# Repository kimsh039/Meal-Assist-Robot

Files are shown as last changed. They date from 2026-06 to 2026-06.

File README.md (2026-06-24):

# 🦾 LUMEN: 3D프린팅 기술을 활용한 인체공학적 다관절 식사 보조 로봇팔
> **"누구나, 언제, 어디서나 스스로 식사할 수 있는 세상"**

인하대학교 **LUMEN(사람의 삶을 밝히는 기술)** 팀이 개발한 **3D프린팅 기반의 인체공학적 다관절 식사 보조 로봇팔** 프로젝트입니다. 상지 장애인, 노약자, 근골격계 환자 등 식사 자립이 어려운 분들의 독립적인 일상을 지원하며, AI 비전 인식 및 음성 제어 기술을 결합하여 저비용·경량·고정밀·안전성을 모두 만족하는 인간 중심 지능형 보조 로봇 시스템을 구현했습니다.

본 프로젝트는 **2025 창의적 종합설계 경진대회**에서 **장관상(2등)**을 수상하였습니다.

---
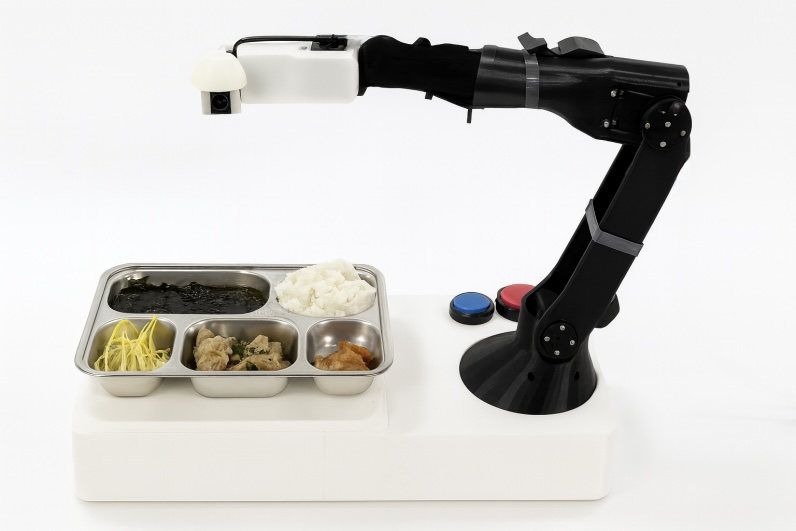
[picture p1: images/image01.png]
product


## 🏆 수상 실적
- **대회명**: 2025 캡스톤 디자인 및 창의아이디어 경진대회
- **상격**: **대상**
- **대회명**: 2025 인하 종합설계 경진대회 (인하공학교육혁신센터 주최/주관)
- **상격**: **인하대학교 총장상** 
- **대회명**: 2025 창의적 종합설계 경진대회 본선
- **상격**: **장관상(2등)**

---

## ✨ 핵심 특장점
- **정확성 (AI Vision)**: AI 카메라가 음식 종류와 입 위치를 실시간으로 인식하여 사용자 맞춤 최적 궤적을 생성합니다.
- **안전성 (Safety First)**: ISO 13850 국제표준 기반 비상정지 시스템과 전류센서 감지를 통해 이상 발생 시 0.1초 내로 전원을 긴급 차단합니다.
- **경량성 (Lightweight)**: 3D프린팅(PLA) 부품 설계로 전체 무게를 약 **1.5 kg** 이하로 구현하여 기존 금속 프레임 대비 약 60% 경량화 및 높은 휴대성을 확보했습니다.
- **경제성 (Cost-Effective)**: 제작 단가를 약 60~70% 절감하여 기존 고가의 해외 제품(1,000만 원 이상) 대비 압도적인 가격 경쟁력(400만 원 이하 공급 가능)을 가집니다.
- **확장성 (Smart Healthcare)**: 보호자용 앱을 통해 실시간 식사 영상을 모니터링하고 영양 및 식습관 데이터를 관리할 수 있습니다.

---

## ⚙️ 시스템 아키텍처 및 주요 기술

### 1. 하드웨어 & 인체공학 설계
- **다관절 구조 (6 DOF)**: 인체 팔의 움직임을 모사하여 숟가락의 궤적이 접시에서 입까지 자연스럽게 연결되도록 설계 (Inventor 및 NX 활용).
- **하이브리드 제어 인터페이스**: 사용자의 신체 조건에 맞춰 선택할 수 있는 3종 조작 방식(풋스위치, 손스위치, 마이크) 제공.
- **지속성**: 2주 이상 사용 가능한 고효율 배터리 탑재.

### 2. AI 비전 및 소프트웨어 시스템
- **음식 객체 인식**: `YOLOv8` 모델을 적용하여 식사 종류(국밥, 반찬, 죽 등)를 탐지하고 포크/스푼 모션을 자동 전환.
- **입 위치 추적 (Mouth Tracking)**: 실시간으로 사용자의 얼굴 및 입 좌표를 추적하여 정밀한 음식 전달 궤적 자동 계산.
- **음성 명령 인터페이스**: LLM 기반 음성명령 제어를 통해 손을 쓰지 않고도 원활한 식사 동작 수행 가능.

### 3. 제어 알고리즘
- **역기구학 (Inverse Kinematics)**: 다자유도 좌표 계산 및 회전각 제어 알고리즘 구현.
- **부드러운 궤적 생성**: Quadratic Programming 알고리즘을 활용하여 모터의 가속도를 최소화하고 흔들림 없는 안정적인 식사 동작 구현.
- **고정밀 제어**: FOC(Field-Oriented Control) 기반 모터 제어로 관절별 제어 정확도 `±0.5°` 이내 유지.

---

## 🛠️ 기술 스택 (Tech Stack)
- **Hardware**: Arduino, Raspberry Pi, Jetson Orin Nano, FOC Motor, Custom 3D Printed Parts (PLA)
- **Software & Control**: Python, C++, ROS (Robot Operating System)
- **AI & Vision**: YOLOv8, OpenCV, MediaPipe (Mouth Tracking), LLM (Voice Control)
- **3D Modeling**: Autodesk Inventor, Siemens NX

---

## 👥 팀원 및 역할 분담 (LUMEN)

| 성명 | 역할 | 담당 업무 |
| :--- | :--- | :--- |
| **조예은** | **PM** | 프로젝트 PM, 전체 일정 관리 및 기획 통합 |
| **전병철** | **하드웨어 제작** | 다관절 로봇팔 메커니즘 설계 및 하드웨어 통합 |
| **박원빈** | **제어 제작** | 임베디드 시스템 구축, 역기구학 및 모터 제어 알고리즘 구현 |
| **이상현** | **인공지능 제작** | YOLOv8 기반 음식 인식 및 입 위치 추적(Mouth Tracking) 모델 개발 |
| **김소희** | **제어 시스템 제작** | 전기회로 설계, 센서 연동 및 인터페이스 제어 보조 |
| **강수영** | **하드웨어 설계/제작** | Inventor/NX 활용 3D 모델링 및 3D 프린팅 부품 가공 |

---

## 📈 시장성 및 기대효과
- **B2B & B2C 시장 진출**: 요양병원, 재활시설 등 의료기관 납품(B2B)과 가정용 보조기기 판매(B2C) 구조 구축.
- **AI 헬스케어 연계**: 축적된 사용자의 식습관 및 영양 데이터를 활용하여 장기적인 맞춤형 디지털 헬스케어 서비스로 확장 가능.
- **사회적 가치**: 돌봄 인력 부족 문제 해결 및 사회적 약자의 자립적 환경 조성으로 인간 존엄성 회복 기여.

---

## 📚 참고문헌
1. 보건복지부(2024), "보건복지통계연보".
2. Ho-Chull Lee, Yong-Kwan Ji, & Jahng-Hyon Park(2019), "Geometric Analysis of Inverse Kinematics and Control for 7-DOF Robot Arm", 대한기계학회.
3. Minchang Sung & Youngjin Choi(2020), "Smooth Trajectory Generation Method Using Quadratic Programming", 한국로봇학회.

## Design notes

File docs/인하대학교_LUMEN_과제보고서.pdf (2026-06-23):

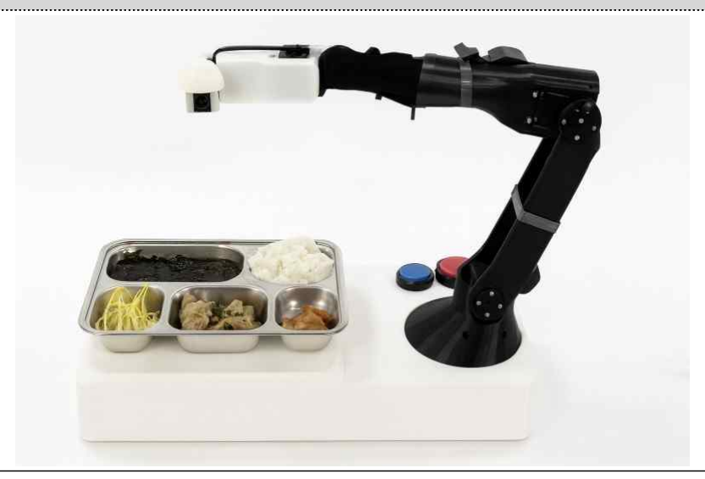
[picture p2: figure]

- 1 -

# 「2025 창의적 종합설계 경진대회」과제보고서

대 학 명 | 인하대학교 | 팀 명 | 국문 루멘 영문 LUMEN(사람의 삶을 밝히는 기술)
작 품 명 | 국문 3D프린팅 기술을 활용한 인체공학적 다관절 식사 보조 로봇팔 영문 A 3D-Printed Ergonomic Multi-Joint Assistive Robotic Arm for eating
제작기간 | 2025년 4월 28일 ~ 2025년 10월 28일
참가분야 | ■ 일 반 □ 다학제융합형 ■ 산학협력형* (산업체인사멘토링) ■ 사회기여형* (사회적약자 기여형)
지식재산권 | □ 해당 ■ 해당없음
포상실적 | 대회명 | 주최/주관 | 상격 | 수상일시 | 부상내역
2025 인하 종합설계 경진대회 | 인하공학교육혁신센터 | 인하대학교 총장상 | 2025.09.11 | 상금 80만원

작품
내용요약

식사 보조가 필요한 인구가 지속적으로 증가하는 가운데, 상지 장애나 근골격계 질환, 노화 등으로 인해 스스로 식사하기 어려운 사람들은 일상 속 자존감 상실과 돌봄 부담의 문제를 겪고 있다. 이러한 사회적 요구에 대응하기 위해 개발된 인체공학적 다관절 식사 보조 로봇 팔은 3D프린팅 기술을 활용해 경량화와 맞춤 설계를 구현하고, AI 기반 시각 인식 및 음성 제어 시스템을 결합하여 누구나 손쉽게 사용할 수 있는 식사 보조 솔루션을 제시한다. 로봇팔은 YOLOv8 기반 음식 객체 인식과 입 위치 추적 기술을 통해 사용자의 동작을 실시

간 분석하고, 음성 명령 또는 스위치 입력만으로 정확하고 부드러운 식사 동작을 수행한다. 또한 ISO 13850 국제표준에 따라 긴급정지 기능을 탑재하여 사용 중 사고를 방지하고, 1.5 kg

이하의 경량 구조와 2주 이상 사용 가능한 배터리를 적용해 휴대성과 안정성을 동시에 확보 하였다. 3D프린팅 부품 사용으로 제작 단가를 약 60% 절감했으며, 다양한 신체 조건에 맞춘 맞춤형 생산이 가능하다. 이러한 기술적 접근을 통해 사용자는 타인의 도움 없이 독립적인 식사를 경험할 수 있고, 보호자는 전용 애플리케이션을 통해 식사 영상을 실시간으로 확인하 며 영양 데이터를 관리할 수 있다. 복지 및 의료 산업 규모는 국내 약 3조 원, 해외 약 40조 원 이상으로 형성되어 있어 시장

성장 잠재력이 크다. 기존 제품 대비 낮은 가격과 높은 범용성을 기반으로 B2B(요양병원·재 활시설)와 B2C(가정용) 시장 진출이 가능하며, 장기적으로는 AI 헬스케어 서비스와 연계한 지 속 가능한 수익 창출 구조를 구축할 수 있다. 이 로봇팔은 단순한 보조기기를 넘어, 경제성 과 기술혁신, 인간 존엄의 회복을 동시에 실현하는 차세대 복지 로봇으로서의 의의를 지닌다. 작품사진

- 2 -

### 1. 과제의 목적, 개발동기 및 필요성

LUMEN이 수행한‘3D프린팅 기술을 활용한 인체공학적 다관절 식사 보조 로봇팔’은 상지 장애인, 노약자, 근골격계 환자 등 식사 자립이 어려운 사람들의 자립적 식사 활동을 지원하기 위해 고안되었

다. AI 기반의 인식 기술과 인체공학적 설계, 3D프린팅 제작 방식을 결합하여 저비용·경량·고정 밀·안전성을 모두 만족시키는 것이 핵심 목표이다. 현재 국내 약 91만 명이 식사 자립에 어려움을 겪고 있으며, 간병인 부족 및 고비용(월 400만 원 이상)의 돌봄 구조로 인해 사회적 부담이 심화되고 있다. 또한 기존 식사 보조 로봇은 대부분 고가(1,000만 원 이상)이거나 전용 식기만 사용 가능한 제 한된 구조를 갖고 있어 실제 보급이 어렵다. 이러한 문제 인식에서 출발한 LUMEN의 로봇팔은‘누구 나, 언제, 어디서나 스스로 식사할 수 있는 세상’을 구현하기 위해 개발되었다. 이 시스템은 YOLOv8 기반 음식 객체 인식, 입 위치 추적(Mouth Tracking), LLM 기반 음성명령 제

어 등을 결합해 사용자의 상황에 따라 정밀하게 동작하며, ISO 13850 국제표준 기반 긴급정지 기능, 2주 이상 사용 가능한 배터리, 경량 구조를 통해 안전성과 휴대성을 동시에 확보했다. 또한 3D프린팅 을 활용해 금속 구조물 대비 제작비를 대폭 절감하고, 사용자의 신체 조건에 맞춘 맞춤형 설계를 가 능하게 했다. 기존 식사 보조 로봇(예: 미국 OBI Eating Device, 스웨덴 Bestic, 특허 US 9066615B2 및 WO

2022055443A1 등)은 대체로 금속 기반 구조에 고가 부품을 사용하고, 전용 식기나 고정된 자세를 필 요로 하는 한계가 있었다. 이에 비해 LUMEN 로봇팔은 3D프린팅 경량화, 다관절 구조를 통한 자연스 러운 움직임, AI·음성인식 통합 인터페이스, 범용 식기 호환성, 낮은 제작비 등에서 확연한 차별성을 지닌다. 단순한 보조기기 개발을 넘어, 경제적 부담을 낮추고 인간의 존엄과 자립을 회복시키는 복지기술 실

현을 목표로 한다. LUMEN의 로봇팔은 기술적 혁신성과 사회적 가치 모두를 충족하는 인간 중심 지 능형 보조 로봇 시스템으로, 고령화 사회의 돌봄 문제 해결과 지속 가능한 복지기술의 방향을 제시한

### 다. 2. 과제의 해결방안 및 수행과정

본 과제의 핵심 해결방안은‘사용자 친화적·경제적·정밀한 식사 보조 로봇팔’을 구현하는 것이 다. 이를 위해 인체공학 설계, 3D프린팅 기반 하드웨어 제작, AI 비전 인식 및 음성 인터페이스 결합 을 중심으로 연구를 수행하였다.

1) 하드웨어 설계 및 3D프린팅 제작
로봇팔의 주요 구조물은 PLA 재질의 3D프린팅 부품으로 구성되어, 금속 프레임 대비 약 60%의 경량 화와 50% 이상의 비용 절감을 달성하였다. Inventor 및 NX 프로그램을 이용하여 다관절(6 DOF) 구조 를 설계하였으며, 인체 팔의 움직임을 모사하여 숟가락의 궤적이 자연스럽게 입으로 전달되도록 하였 다. 풋스위치, 손스위치, 마이크 등 3종 제어방식(선택형)을 제공하여 사용자의 신체 조건에 맞춘 조 작이 가능하도록 하였다.
2) AI 비전 시스템 구축
YOLOv8 모델을 적용하여 음식 객체를 탐지하고, 식사의 종류(국밥, 반찬, 죽 등)에 따라 포크/스푼 모션을 자동 전환한다. 입 위치 추적(Mouth Tracking) 기술을 적용하여 사용자의 얼굴 및 입 좌표를 실시간으로 인식하고, 음식 전달 궤적을 자동 계산한다. 이를 통해 사용자는 단순히 버튼을 누르거나 음성 명령을 하는 것만으로 안정적인 식사가 가능하다.

- 3 -
3) 제어 알고리즘 및 안전 기능 구현
로봇 모터 전류와 관절 각도를 실시간 감시하여 이상 신호 발생 시 0.1초 이내 긴급정지(ISO 13850 기반) 기능을 수행하도록 설계하였다. 또한 보호자용 앱을 개발하여 카메라 영상 실시간 모니터링 및 식습관 데이터 전송 기능을 포함시켰다.
4) 검증 및 개선 과정
프로토타입 제작 후, 인하대학교병원 및 국립재활공학연구소 자문을 받아 조작성, 위생성, 안전성 평 가를 수행하였다. 실사용 피드백을 통해 로봇팔의 관절 가속도, 속도, 스푼 각도를 반복 보정하였다. 결과적으로 과제의 수행과정은‘3D프린팅 제작 → 인체공학 설계 → AI 비전 인식 → 안전제어 및

검증’의 순환 구조를 기반으로 하며, 사용자의 실제 환경에서 안정적이고 자율적인 식사가 가능하도 록 체계적으로 완성되었다.

그림 2 (전기회로도) 그림 3 (음식객체 탐지)

### 3. 과제의 내용

1) 이론적·기술적 근거
- 역기구학(Inverse Kinematics) 기반 다관절 제어
Ho-Chull Lee 외(대한기계학회, 2019)의‘Geometric Analysis of Inverse Kinematics and Control for 7-DOF Robot Arm’을 참고하여, 다자유도(6 DOF) 로봇팔의 좌표 계산 및 회전각 제어 알고리즘을 구현하였다. - Smooth Trajectory Generation (Quadratic Programming)

Sung & Choi(2020)의 연구를 바탕으로, 로봇 관절의 가속도를 최소화하여 부드럽고 안정적인 식사 동 작 궤적을 생성하였다. - 인체공학 설계 및 사용자 중심 설계

사람의 어깨–팔–입 궤적 데이터를 분석해 인간의 자연스러운 식사 동작을 모사함으로써 장시간 사용 에도 피로도가 낮은 설계를 적용하였다.

2) 개념설계 및 상세설계
- 개념설계
‘누구나 쉽게 사용할 수 있는 경량형 로봇팔’을 기본 철학으로, 다관절 구조를 통해 ‘접시 → 입’까지의 3차원 궤적을 단 2개의 입력으로 수행하도록 설정하였다. 3D프린팅 부품으로 구성된 모

듈형 구조를 채택하여 수리·교체가 용이하고, 사용자의 신체 크기에 맞춰 확장 가능한 구조로 설계 하였다. - 상세설계

Inventor/NX 프 로 그 램 을 이 용 해 각 관 절 별 회 전 각 (θ1~θ7)을 계 산 하 고 , 모 터 토 크 및 속 도 를 최 적 화 하 였다. FOC(Field-Oriented Control) 기반 모터제어를 적용하여 관절별 제어정확도를 ±0.5° 이내로 유 지하였다. Arduino + Raspberry Pi 기반 임베디드 시스템을 통해 카메라 영상 처리, 음성 입력, 모터 제어를 통합 제어하였다.

- 4 -
3) 결과물의 특장점 및 수행내용
- 정확성: AI 카메라가 음식 종류와 입 위치를 실시간으로 인식하여 사용자 맞춤 궤적을 생성함. - 안전성: ISO 13850 기반 비상정지, 전류센서 감지 시스템을 통해 0.1초 내 긴급 차단 가능. - 경량성: 전체 무게 약 1.5 kg으로 타사 제품 대비 두 배 이상 가벼움. - 경제성: 3D프린팅 제작으로 원가를 약 70% 절감. - 확장성: 앱을 통한 데이터 전송 및 보호자 모니터링 기능으로 복지·의료기관 확장 가능. 4. 기대효과 및 활용 방안
1) 실용성
상지 장애인, 노약자, 근골격계 질환자 등 식사 보조가 필요한 광범위한 대상에게 적용 가능하다. 또 한 휴대가 간편하고 조작이 단순해 가정, 요양시설, 재활병원 등 다양한 환경에서 실사용이 가능하다. 보호자용 앱을 통한 모니터링 기능으로 실시간 안전 확인과 영양 데이터 관리가 가능하다.
2) 시장성 및 경제성
국내 복지보조기기 시장은 약 3,400억 원, 의료기기 산업은 3조 원 이상 규모로 매년 성장 중이다. 해외 보조기기 시장은 약 329억 달러(약 44조 원) 규모로 형성되어 있으며, 고령화에 따라 꾸준히 확

대되는 추세이다. 기존 제품(1,000만 원 이상)에 비해 3D프린팅 기반 제작으로 400만 원 이하 공급 가 능하여 가격 경쟁력이 높다. 또한 저가·고효율 구조 덕분에 서비스화 시에도 마진이 충분히 확보 가 능한 경제성을 갖춘다.

3) 사업화 및 지속가능성
B2B 모델(요양병원, 재활병원 납품)과 B2C 모델(가정용 보조기기 판매)을 병행하여 수익구조를 다변 화할 수 있다. 사용자의 데이터(식사 빈도, 식습관 등)를 활용한 AI 맞춤형 헬스케어 서비스 확장도 가능하다. 유지보수가 간단하고 3D프린팅 부품 교체만으로 지속 운영이 가능해 장기적 유지비가 적 고 지속가능한 수익모델로 발전할 수 있다. 5. 비용분석 및 팀원 간 역할 분담

비용 분석
항목 | 세부항목 | 소요비용 (천원)
시제품가공비 | 3D 프린팅 | 150
재료비 | 모터, 스위치, 잿슨오린나노, 마이크 등 | 2,569
합 계 | | 2,719

팀원 간 역할 분담
성명 | 역할 | 참여도 (%)
조예은 | 전체 총괄 | 25%
전병철 | 하드웨어 팀장 | 20%
박원빈 | 제어 팀장 | 20%
이상현 | 인공지능 팀장 | 15%
김소희 | 제어 시스템 제작 | 10%
강수영 | 하드웨어 설계 및 제작 | 10%
함 계 | | 100%

### 6. 참고문헌

1. 보건복지부(2024, 06), “보건복지통계연보”, 「보건복지부 공식 통계자료」, 보건복지부
2. Ho-Chull Lee, Yong-Kwan Ji, & Jahng-Hyon Park(2019, Oct), “Geometric Analysis of Inverse Kinematics and Control for 7-DOF Robot Arm”, The Korean Society of Mechanical Engineers.
3. Minchang Sung & YouMethngjin Choi(2020, Mar), “Smooth Trajectory Generation Method Using Quadratic Programming od”, The Korea Robotics Society.

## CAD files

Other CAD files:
cad/ARM_1 SKETCH.ipt
cad/ARM_1 SKETCH_smooth.ipt
cad/ARM_2 SKETCH - smooth.ipt
cad/ARM_2 SKETCH.ipt
cad/ARM_3 SKETCH.ipt
cad/FR05-H101.ipt
cad/FR08-H101 - mx106 frame.ipt
cad/MX-106T.ipt
cad/MX-28T.ipt
cad/MX-64R.ipt
cad/MX106 FRAME.ipt
cad/MX64 FRAME.ipt
cad/MX64 MOTOR CASE.ipt
cad/PLATE 1.ipt
cad/PLATE 2.ipt
cad/end effector 2.ipt
cad/end effector.ipt
cad/fr07_h101 - mx28 frame.ipt
cad/motor cover1.ipt
cad/plate cover 1.ipt
cad/plate cover 2.ipt

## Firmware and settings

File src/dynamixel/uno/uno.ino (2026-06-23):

#include <Wire.h>
#include "DynamixelConfig.h"
#include "MealAssistant.h"

constexpr uint8_t kCommandQueueSize = 8;
volatile uint8_t commandQueue[kCommandQueueSize];
volatile uint8_t commandHead = 0;
volatile uint8_t commandTail = 0;
MealAssistant assistant;

void receiveCommand(int byteCount)  // I2C 수신 인터럽트를 처리한다
{
  if (byteCount > 0 && Wire.available() > 0)
  {
    const uint8_t value = static_cast<uint8_t>(Wire.read());

    const uint8_t nextHead = static_cast<uint8_t>((commandHead + 1) % kCommandQueueSize);

    if (value >= 1 && value <= 7 && nextHead != commandTail)
    {
      commandQueue[commandHead] = value;
      commandHead = nextHead;
    }
  }

  while (Wire.available() > 0)
  {
    Wire.read();
  }
}

void setup()  // 장치 초기화 진입점이다
{
  Wire.begin(DynamixelConfig::kI2cAddress);
  Wire.onReceive(receiveCommand);
  assistant.begin();
}

bool dequeueCommand(uint8_t& command)  // 버튼으로 전달된 다음 명령을 꺼낸다
{
  if (commandTail == commandHead)
  {
    return false;
  }

  noInterrupts();
  command = commandQueue[commandTail];
  commandTail = static_cast<uint8_t>((commandTail + 1) % kCommandQueueSize);
  interrupts();
  return true;
}

void loop()  // 반복 실행 진입점이다
{
  uint8_t command;

  if (dequeueCommand(command))
  {
    assistant.execute(command);
  }
}

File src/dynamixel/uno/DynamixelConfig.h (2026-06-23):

#ifndef DYNAMIXEL_CONFIG_H
#define DYNAMIXEL_CONFIG_H

#include <Arduino.h>
#include "RobotTypes.h"

namespace DynamixelConfig
{
constexpr uint8_t kI2cAddress            = 0x12;              // Uno I2C 슬레이브 주소
constexpr uint8_t kDirectionPin          = 2;                 // 반이중 통신 방향 핀
constexpr uint32_t kBusBaud              = 57600UL;           // 다이나믹셀 버스 속도
constexpr float kProtocolVersion         = 2.0f;              // 다이나믹셀 프로토콜 버전
constexpr uint16_t kTorqueAddress        = 64;                // Torque Enable 주소
constexpr uint16_t kAccelerationAddress  = 108;               // Profile Acceleration 주소
constexpr uint16_t kVelocityAddress      = 112;               // Profile Velocity 주소
constexpr uint32_t kProfileAcceleration  = 50UL;              // 기본 프로파일 가속도
constexpr uint32_t kProfileVelocity      = 120UL;             // 기본 프로파일 속도
constexpr uint8_t kIds[6]                = {1, 2, 3, 4, 5, 6};  // 관절별 모터 ID

constexpr float kBaseHeight = 70.0f;   // 베이스 높이
constexpr float kUpperArm   = 200.0f;  // 상박 링크 길이
constexpr float kForearm    = 180.0f;  // 하박 링크 길이

constexpr uint16_t kTrajectorySteps = 100;      // 궤적 보간 구간 수
constexpr uint32_t kArmStepUs        = 20000UL;  // 팔 궤적 단계 시간
constexpr uint32_t kToolStepUs       = 2000UL;   // 도구 회전 단계 시간

constexpr int32_t kInitialRaw[6] = {1820, 2200, 2150, 1800, 2048, 2048};  // 전원 직후 모터 위치
constexpr Point3 kInitialPoint    = {0.0f, 0.0f, 450.0f};                  // 전원 직후 가정 좌표
constexpr Point3 kOffPoint        = {0.0f, 10.0f, 200.0f};                 // 전원 대기 좌표
constexpr Point3 kReadyPoint      = {30.0f, 100.0f, 300.0f};               // 사용자 앞 대기 좌표
constexpr Point3 kPlateOnePoint   = {-20.0f, 50.0f, 140.0f};               // 첫 번째 식판 좌표
constexpr Point3 kPlateTwoPoint   = {-20.0f, 200.0f, 140.0f};              // 두 번째 식판 좌표
constexpr Point3 kPlateThreePoint = {-110.0f, 240.0f, 140.0f};             // 세 번째 식판 좌표

constexpr int32_t kToolCenterRaw      = 2048;    // 도구 중앙 위치
constexpr int32_t kToolForkFirstRaw   = 530;     // 포크 첫 번째 회전 위치
constexpr int32_t kToolForkSecondRaw  = 0;       // 포크 두 번째 회전 위치
constexpr int32_t kToolSpoonRaw       = 2554;  // 숟가락 회전 위치
}

#endif

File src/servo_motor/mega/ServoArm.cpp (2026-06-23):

#include "ServoArm.h"

#include <math.h>

void ServoArm::begin()  // PWM 장치를 초기화한다
{
  configureTimers();

  for (uint8_t index = 0; index < 6; ++index)
  {
    currentPulses_[index] = ServoConfig::kInitialPulses[index];
  }

  writePulses(currentPulses_);
}

void ServoArm::moveTo(const ServoConfig::JointPose& pose)  // 여섯 관절을 동시 보간한다
{
  float targetPulses[6];
  float startPulses[6];
  float maximumDelta = 0.0f;

  calculatePulses(pose, targetPulses);

  for (uint8_t index = 0; index < 6; ++index)
  {
    startPulses[index] = currentPulses_[index];
    maximumDelta = max(maximumDelta, fabsf(targetPulses[index] - startPulses[index]));
  }

  const uint16_t stepCount = static_cast<uint16_t>(ceilf(maximumDelta));

  if (stepCount == 0)
  {
    return;
  }

  for (uint16_t step = 1; step <= stepCount; ++step)
  {
    const uint32_t deadlineUs = micros() + ServoConfig::kMotionStepUs;
    const float ratio = static_cast<float>(step) / static_cast<float>(stepCount);
    float interpolated[6];

    for (uint8_t index = 0; index < 6; ++index)
    {
      interpolated[index] = startPulses[index] + ((targetPulses[index] - startPulses[index]) * ratio);
    }

    writePulses(interpolated);
    waitUntil(deadlineUs);
  }

  for (uint8_t index = 0; index < 6; ++index)
  {
    currentPulses_[index] = targetPulses[index];
  }
}

void ServoArm::configureTimers()  // Mega 2560의 PWM 타이머를 설정한다
{
  DDRH |= 0b00111000;
  DDRE |= 0b00111000;

  TCCR3A = _BV(WGM31) | _BV(COM3A1) | _BV(COM3B1) | _BV(COM3C1);  // Timer3 Fast PWM 출력 모드를 설정한다
  TCCR3B = _BV(WGM33) | _BV(WGM32) | _BV(CS31) | _BV(CS30);  // Timer3 분주비를 64로 설정한다
  TCCR4A = _BV(WGM41) | _BV(COM4A1) | _BV(COM4B1) | _BV(COM4C1);  // Timer4 Fast PWM 출력 모드를 설정한다
  TCCR4B = _BV(WGM43) | _BV(WGM42) | _BV(CS41) | _BV(CS40);  // Timer4 분주비를 64로 설정한다

  ICR3  = ServoConfig::kPwmTop;  // Timer3 주기를 50Hz로 설정한다
  ICR4  = ServoConfig::kPwmTop;  // Timer4 주기를 50Hz로 설정한다
  TCNT3 = 0;
  TCNT4 = 0;
}

void ServoArm::calculatePulses(const ServoConfig::JointPose& pose, float pulses[6]) const  // 각도를 보정 PWM으로 변환한다
{
  pulses[0] = 17.0f  + ((270.0f - pose.joint1) * 500.0f / 270.0f);  // 1번 관절 보정값을 적용한다
  pulses[1] = 166.0f + (pose.joint2 * 500.0f / 270.0f);  // 2번 관절 보정값을 적용한다
  pulses[2] = 117.0f + ((270.0f - pose.joint3) * 500.0f / 270.0f);  // 3번 관절 보정값을 적용한다
  pulses[3] = 120.0f + ((180.0f - pose.joint4) * 500.0f / 180.0f);  // 4번 관절 보정값을 적용한다
  pulses[4] = 138.0f + ((180.0f - pose.joint5) * 500.0f / 180.0f);  // 5번 관절 보정값을 적용한다
  pulses[5] = 145.0f + (pose.joint6 * 500.0f / 180.0f);  // 6번 관절 보정값을 적용한다
}

void ServoArm::writePulses(const float pulses[6])  // 여섯 PWM 출력을 갱신한다
{
  OCR4A = static_cast<uint16_t>(pulses[0]);  // 1번 서보 PWM을 기록한다
  OCR4B = static_cast<uint16_t>(pulses[1]);  // 2번 서보 PWM을 기록한다
  OCR4C = static_cast<uint16_t>(pulses[2]);  // 3번 서보 PWM을 기록한다
  OCR3A = static_cast<uint16_t>(pulses[3]);  // 4번 서보 PWM을 기록한다
  OCR3B = static_cast<uint16_t>(pulses[4]);  // 5번 서보 PWM을 기록한다
  OCR3C = static_cast<uint16_t>(pulses[5]);  // 6번 서보 PWM을 기록한다
}

void ServoArm::waitUntil(uint32_t deadlineUs) const  // 마이크로초 기준 시각까지 기다린다
{
  while (static_cast<int32_t>(micros() - deadlineUs) < 0)
  {
  }
}

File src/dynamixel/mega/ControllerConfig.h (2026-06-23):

#ifndef DYNAMIXEL_CONTROLLER_CONFIG_H
#define DYNAMIXEL_CONTROLLER_CONFIG_H

#include <Arduino.h>

namespace ControllerConfig
{
constexpr uint8_t kEnablePin       = 53;        // 외부 회로 활성 출력
constexpr uint8_t kRedButtonPin    = 51;        // 식판 위치 선택 버튼
constexpr uint8_t kBlueButtonPin   = 49;        // 상하 및 식사 동작 버튼
constexpr uint8_t kPowerSwitchPin  = 47;        // 전원 상태 입력
constexpr uint32_t kSerialBaud     = 115200UL;  // PC 디버그 통신 속도
constexpr uint32_t kCommandDelayMs = 1000UL;    // 상태 명령 처리 대기 시간
}

#endif
